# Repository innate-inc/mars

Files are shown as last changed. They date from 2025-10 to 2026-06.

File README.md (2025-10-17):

<div align="center">

<!-- Add your banner image here -->
<!-- ![Mars Robot Banner](./assets/banner.png) -->

# Mars - A Personal AI Robot

*Complete design files and documentation for the Mars robot platform*







</div>

---

> [!WARNING]
> **This is an alpha release** - Breaking changes may occur. DIY builds are as-is without warranty.
> Purchase from us for guaranteed upgrades and full support.

---

## Philosophy

At Innate, we believe every builder should be a part of the robotics revolution, just like they were for the Personal Computer revolution.

To do so, two things are required: making robots **affordable**, but also **intuitive** and **powerful** to build with. MARS is our first platform and comes with every compute and sensor required for a general-purpose robot: navigation, manipulation, interaction with the best of AI.

With it, you can run (and build) VLAs, embodied agents, world models, and every other crazy idea you might have, for a BOM <$1k!

## Key Specifications

### Robotic Arm
- **Degrees of Freedom**: 5-DOF manipulator with modular end effector
- **Reach**: 10 inches (254mm) maximum
- **Payload**: 200g at full extension
- **Integrated Camera**: 150° field of view for vision-based manipulation

### Power
- **Battery Life**: ~5 hours with all systems running (navigation, manipulation, compute) using an 8000mAh battery*
  
*Battery delivered by Innate

For complete specifications, visit the [official documentation](https://docs.innate.bot).

## Repository Structure

This repository contains all the hardware design files you need to build a Mars robot:

### 📁 [Printed Parts](printed-parts/)
3D printable components including shells, layers, arm links, head, and mounting hardware. See the [printed-parts README](printed-parts/README.md) for details.

### 📁 [PCBs](pcbs/)
KiCad projects and production files for the head PCB and main development board. See the [pcbs README](pcbs/README.md) for details.

### 📄 Documentation
- **[Bill of Materials](BOM.md)** - Complete parts list with sourcing information
- **[Assembly Guide](assemblies.zip)** - Step-by-step assembly instructions

## Getting Started

1. **Review the [Bill of Materials](BOM.md)** - Source all required components
2. **Order PCBs** - See [pcbs/README.md](pcbs/README.md) for manufacturing instructions  
3. **3D Print Parts** - See [printed-parts/README.md](printed-parts/README.md) for printing guidelines
4. **Assemble** - Follow the instructions in [assemblies.zip](assemblies.zip)

## Contributing

We welcome contributions from the community! Feel free to:
- 🐛 Report bugs and issues
- 💡 Suggest new features and improvements
- 🔧 Submit pull requests
- 📖 Improve documentation

Please join our [Discord community](https://discord.gg/your-invite-link) to discuss your ideas before making major changes.

---

## 📜 License

This project uses dual licensing to cover hardware and software components:

### Hardware License: CERN-OHL-S-2.0

All hardware designs, PCB files, 3D models, and related documentation in this repository are licensed under the **CERN Open Hardware Licence Version 2 - Strongly Reciprocal** (CERN-OHL-S-2.0).

This is a copyleft license that ensures any modifications or derivative works must also be released under the same license, promoting open collaboration while protecting the open-source nature of the hardware.

📄 [View Hardware License](LICENSE-HARDWARE)  
🔗 [Learn more about CERN-OHL-S](https://ohwr.org/cern_ohl_s_v2.txt)

### Software License: GPL v3

The software components for this robot (to be released separately) are licensed under the **GNU General Public License v3.0** (GPL v3).

This ensures that any software modifications or derivative works remain open source and available to the community.

📄 [View Software License](LICENSE-SOFTWARE) *(Software repository coming soon)*  
🔗 [Learn more about GPL v3](https://www.gnu.org/licenses/gpl-3.0.en.html)

---

<div align="center">

**Built with 💙 by Innate in Palo Alto, California**

[Discord](https://discord.gg/your-invite-link) • [Documentation](https://docs.yoursite.com) • [Website](https://yourwebsite.com)

</div>

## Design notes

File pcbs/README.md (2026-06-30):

# PCBs

KiCad project files and production-ready outputs for all Mars robot circuit boards.

## 📋 Boards

### Head PCB
**Location**: `head-pcb/`

The head PCB controls sensors and actuators in the robot's head assembly.

- **KiCad Project**: [leader.kicad_pro](head-pcb/leader.kicad_pro)
- **Schematic**: [leader.kicad_sch](head-pcb/leader.kicad_sch)
- **PCB Layout**: [leader.kicad_pcb](head-pcb/leader.kicad_pcb)

**Production Files** (`head-pcb/production/`):
- [Gerbers & Drill Files](head-pcb/production/leader.zip)
- [BOM (Bill of Materials)](head-pcb/production/bom.csv)
- [Component Positions](head-pcb/production/positions.csv)
- [Designators Reference](head-pcb/production/designators.csv)
- [IPC Netlist](head-pcb/production/netlist.ipc)

### Main Development Board
**Location**: `main-dev-board/`

The main development board is the brain of the robot, handling computation and motor control."C:\Users\nick\Documents\Innate\mars\pcbs\main-dev-board\MARS%20Dev%20Board.kicad_pro"

- **KiCad Project**: [innate dev pcb.kicad_pro](main-dev-board/MARS%20Dev%20Board.kicad_pro)
- **Schematic**: [innate dev pcb.kicad_sch](main-dev-board/MARS%20Dev%20Board.kicad_sch)
- **PCB Layout**: [innate dev pcb.kicad_pcb](main-dev-board/MARS%20Dev%20Board.kicad_pcb)
- **3D Model**: [innate dev pcb.step](main-dev-board/MARS%20Dev%20Board.step)

**Production Files** (`main-dev-board/production/`):
- [Gerbers & Drill Files](main-dev-board/production/MARS_Dev_Board.zip)
- [BOM (Bill of Materials)](main-dev-board/production/bom.csv)
- [Component Positions](main-dev-board/production/positions.csv)
- [Designators Reference](main-dev-board/production/designators.csv)
- [IPC Netlist](main-dev-board/production/netlist.ipc)

## Design Modifications

To modify the PCB designs:
1. Install [KiCad 7.0+](https://www.kicad.org/)
2. Open the `.kicad_pro` file in KiCad
3. Make your changes to schematic and/or layout
4. Regenerate production files using KiCad's fabrication output tools

## 📐 Fabrication Toolkit

Both boards include `fabrication-toolkit-options.json` for automated production file generation.

## ⚡ Important Notes

- Always verify board revisions match your BOM
- Double-check component orientations before assembly
- Test boards thoroughly before integration
- Refer to the [main BOM](../BOM.md) for complete sourcing information

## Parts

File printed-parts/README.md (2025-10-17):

# Printed Parts

All 3D printable components for the Mars robot. Files are provided in STEP format for maximum compatibility.

## 🏗️ Structure Components

### Shells
- **[shell.STEP](shells/shell.STEP)** - Main outer shell

### Layers
- **[layer1.STEP](layers/layer1.STEP)** - Base layer
- **[layer2.STEP](layers/layer2.STEP)** - Second layer
- **[layer3.STEP](layers/layer3.STEP)** - Third layer
- **[Layer4.STEP](layers/Layer4.STEP)** - Top layer

## 🦾 Arm Components

### Arm Links
- **[link1.STEP](arm/link1.STEP)** - Base link
- **[link2.STEP](arm/link2.STEP)** - Second link
- **[link3.STEP](arm/link3.STEP)** - Third link
- **[link4.STEP](arm/link4.STEP)** - Fourth link
- **[link5.STEP](arm/link5.STEP)** - Fifth link
- **[link61.STEP](arm/link61.STEP)** - Sixth link part 1
- **[link62.STEP](arm/link62.STEP)** - Sixth link part 2

## 🤖 Head Components

- **[head.STEP](heads/head.STEP)** - Robot head assembly

## 🔧 Layer Components

- **[batter_holder_2_cover.STEP](layer-components/batter_holder_2_cover.STEP)** - Battery holder cover
- **[usb_holder.STEP](layer-components/usb_holder.STEP)** - USB cable holder

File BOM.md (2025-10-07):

# Bill of Materials (BOM)

## PRINTED PARTS

| Item | Description | Qty | Link |
|---|---|-----|---|
| 1 | Shell | 1 | [shell.STEP](printed-parts/shells/shell.STEP) |
| 2 | Layer 1 | 1 | [layer1.STEP](printed-parts/layers/layer1.STEP) |
| 3 | Layer 2 | 1 | [layer2.STEP](printed-parts/layers/layer2.STEP) |
| 4 | Layer 3 | 1 | [layer3.STEP](printed-parts/layers/layer3.STEP) |
| 5 | Layer 4 | 1 | [Layer4.STEP](printed-parts/layers/Layer4.STEP) |
| 6 | Head | 1 | [head.STEP](printed-parts/heads/head.STEP) |
| 7 | Battery Cover | 1 | [batter_holder_2_cover.STEP](printed-parts/layer-components/batter_holder_2_cover.STEP) |
| 8 | Link 1 | 1 | [link1.STEP](printed-parts/arm/link1.STEP) |
| 9 | Link 2 | 1 | [link2.STEP](printed-parts/arm/link2.STEP) |
| 10 | Link 3 | 1 | [link3.STEP](printed-parts/arm/link3.STEP) |
| 11 | Link 4 | 1 | [link4.STEP](printed-parts/arm/link4.STEP) |
| 12 | Link 5 | 1 | [link5.STEP](printed-parts/arm/link5.STEP) |
| 13 | Link 6-1 | 1 | [link61.STEP](printed-parts/arm/link61.STEP) |
| 14 | Link 6-2 | 1 | [link62.STEP](printed-parts/arm/link62.STEP) |

## MOTORS and WHEELS

| Item | Description | Manufacturer | Model Number | Qty | Price | Link |
|---|---|---|---|-----|---|---|
| 1 | Dynamixel XL430 | Robotis | XL430-W250-T | 2 | $27.50 | [Product Page](https://www.robotis.us/dynamixel-xl430-w250-t/) |
| 2 | Dynamixel XC430 | Robotis | XC430-T240BB-T | 1 | $137.89 | [Product Page](https://www.robotis.us/dynamixel-xc430-t240bb-t/) |
| 3 | Dynamixel XL330 | Robotis | XL330-M288 | 4 | $27.49 | [Product Page](https://www.robotis.us/dynamixel-xl330-m288-t/) |
| 4 | Waveshare DDSM210 | Waveshare | DDSM210 | 2 | $23.99 | [Product Page](https://www.waveshare.com/ddsm210.htm) |
| 5 | Ball Caster with 3/4″ Metal Ball | Pololu | 955 | 1 | $4.49 | [Product Page](https://www.pololu.com/product/955) |

## CABLES

| Item | Description | Qty | Price | Link |
|---|---|-----|---|---|
| 1 | XT60 Female to T-Plug (Deans) Male Cable 14AWG (8in/200mm) | 1 | $3.99 | [Product Page](https://innov8tivedesigns.com/charge-harness-cable-xt60-female-to-t-plug-male.html) |
| 2 | USB 3.0 Type A to USB C 90 Degree Cable (3.3ft/1m) | 1 | $9.98 | [Product Page](https://a.co/d/eL7heE4) |
| 3 | USB 2.0 to Micro USB Cable (1ft/0.3m) | 1 | $8.99 | [Product Page](https://a.co/d/4h7tGla) |
| 4 | USB 3.0 Type A Male to Male Cable (1.5ft/0.5m) | 1 | $4.99 | [Product Page](https://a.co/d/hsTTd4A) |
| 5 | USB A to USB C Cable 10Gbps (1.6ft) 2-Pack | 1 | $20.78 | [Product Page](https://a.co/d/3ilqBba) |

## SENSORS

| Item | Description | Manufacturer | Model Number | Qty | Price | Link |
|---|---|---|---|-----|---|---|
| 1 | OAK-D W Stereo Depth Camera | Luxonis | OAK-D-W-97 | 1 | $449.99 | [Product Page](https://shop.luxonis.com/products/oak-d-w?variant=44149271265503) |
| 2 | RPLidar A1M8 | Slamtec | A1M8 | 1 | $99.99 | [Product Page](https://www.slamtec.com/en/lidar/a1) |
| 3 | USB Camera | Arducam | B0261 | 1 | $49.99 | [Product Page](https://www.arducam.com/arducam-fisheye-low-light-usb-camera-for-computer-2mp-1080p-imx291-wide-angle-mini-h-264-uvc-video-camera-board-with-microphone.html) |

## LAYER COMPONENTS

| Item | Description | Manufacturer | Qty | Price | Link |
|---|---|---|-----|---|---|
| 1 | Head PCB | JLCPCB | 1 | | [KiCad Project](pcbs/head-pcb/leader.kicad_pro) \| [Production Files](pcbs/head-pcb/production/) |
| 2 | Main PCB | JLCPCB | 1 | | [KiCad Project](pcbs/main-dev-board/innate%20dev%20pcb.kicad_pro) \| [Production Files](pcbs/main-dev-board/production/) |
| 3 | Jetson Orin nano | Nvidia | 1 | $249.00 | [Product Page](https://www.nvidia.com/en-us/autonomous-machines/embedded-systems/jetson-orin/nano-super-developer-kit/) |

## HARDWARE

| Item | Description | Qty |
|---|---|-----|
| 1 | M3x40 Spacers | 9 |
| 2 | M3 Thumb nuts | 4 |
| 3 | M3 x 12 Bolts | 12 |
| 4 | M3 nuts | 20 |
| 5 | M4 x 8 Bolts | 6 |
| 6 | M2.5 x 6 Bolts | 8 |
| 7 | M2.5 x 8 Bolts | 4 |
| 8 | M3 x 8 Bolts | 4 |
| 9 | M3 x 20 Bolts | 4 |
| 10 | M2.5 nuts | 12 |
| 11 | Assorted Hardware | 20 |

## BATTERY

| Item | Description | Manufacturer | Qty | Price | Link |
|---|---|---|-----|---|---|
| 1 | 8000 Mah Lipo | ZEEE Power | 1 | $62.00 | [Product Page](https://a.co/d/5oQBWqG) |

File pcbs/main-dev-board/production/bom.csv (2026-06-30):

Reference | Value | DNP | Exclude from BOM | Exclude from Board | Footprint | LCSC Part #
D2,D5 | SMBJ33CA |  |  |  | SMBJ33CA:DIOM4336X265N | C78420
J7,J19 | 1935161 |  |  |  | TerminalBlock_Phoenix:TerminalBlock_Phoenix_PT-1,5-2-5.0-H_1x02_P5.00mm_Horizontal | C8404
C7 | 10TPB220ML |  |  |  | 10TPB220ML:CAP_10TPB220ML | C347545
L2 | FXL0630-150-M |  |  |  | FXL0630-150-M:INDM7066X300N | C177243
D1 | B340A-13-F |  |  |  | B340A-13-F:DIOM5226X240N | C908680
J6 | XT60PW-M |  |  |  | AMASS_XT60PW-M:AMASS_XT60PW-M | C98732
USB1 | ~ |  |  |  | Connector_USB:USB_C_Receptacle_HRO_TYPE-C-31-M-12 | C165948
U10 | SN74LVC1G125DBV |  |  |  | Package_TO_SOT_SMD:SOT-23-5 | C23654
U9 | AMS1117-3.3 |  |  |  | Package_TO_SOT_SMD:SOT-223-3_TabPin2 | C347222
U8 | CH343P |  |  |  | Package_DFN_QFN:WCH_QFN-16-1EP_3x3mm_P0.5mm_EP1.8x1.8mm | C2846043
U7 | MIC5504-1.8YM5 |  |  |  | Package_TO_SOT_SMD:SOT-23-5 | C3040643
U6 | BTS50010-1TAD |  |  |  | Package_TO_SOT_SMD:TO-263-7_TabPin4 | C2150443
U5 | TPS259482AYWPR |  |  |  | tps25948:YWP0012A-MFG | C22422005
U4 | ICM-20948 |  |  |  | Sensor_Motion:InvenSense_QFN-24_3x3mm_P0.4mm | C726001
U3 | SN74LVC1G126DBV |  |  |  | Package_TO_SOT_SMD:SOT-23-5 | C7834
U2 | MAX98357A |  |  |  | Package_DFN_QFN:TQFN-16-1EP_3x3mm_P0.5mm_EP1.23x1.23mm | C910544
U1 | TPS5430DDA |  |  |  | Package_SO:TI_SO-PowerPAD-8_ThermalVias | C9864
R37,R38 | 100 |  |  |  | Resistor_SMD:R_0402_1005Metric | C25076
R36 | 470 |  |  |  | Resistor_SMD:R_0402_1005Metric | C25167
R35,R40,R41 | 1.8k |  |  |  | Resistor_SMD:R_0402_1005Metric | C25932
R32,R39 | 100k |  |  |  | Resistor_SMD:R_0402_1005Metric | C25741
R28,R29 | 5k1 |  |  |  | Resistor_SMD:R_0402_1005Metric | C25905
R24,R25,R26,R27 | 2.2k |  |  |  | Resistor_SMD:R_0402_1005Metric | C25879
R23 | 1k |  |  |  | Resistor_SMD:R_0402_1005Metric | C11702
R20 | 4 |  |  |  | Resistor_SMD:R_0402_1005Metric | C270603
R18,R19 | 10k |  |  |  | Resistor_SMD:R_0402_1005Metric | C25744
R14 | 42.2k |  |  |  | Resistor_SMD:R_0402_1005Metric | C26979
R13 | 470k |  |  |  | Resistor_SMD:R_0402_1005Metric | C25790
R12 | 887 |  |  |  | Resistor_SMD:R_0402_1005Metric | C474137
R11 | 47k |  |  |  | Resistor_SMD:R_0402_1005Metric | C25792
R10 | 133k |  |  |  | Resistor_SMD:R_0402_1005Metric | C25753
R8,R9,R33,R34 | 10K |  |  |  | Resistor_SMD:R_0402_1005Metric | C25744
R7 | 20K |  |  |  | Resistor_SMD:R_0402_1005Metric | C25765
R6 | 3.24k |  |  |  | Resistor_SMD:R_0603_1608Metric | C22994
R5 | 10k |  |  |  | Resistor_SMD:R_0603_1608Metric | C15401
R3,R21,R22,R30 | 4.7k |  |  |  | Resistor_SMD:R_0402_1005Metric | C25900
R2 | 634K |  |  |  | Resistor_SMD:R_0402_1005Metric | C270588
R1 | 100K |  |  |  | Resistor_SMD:R_0402_1005Metric | C25741
Q5 | CSD18540Q5B |  |  |  | Package_TO_SOT_SMD:TDSON-8-1 | C86513
Q3,Q4,Q6 | 2N7002 |  |  |  | Package_TO_SOT_SMD:SOT-23 | C8545
Q1 | MMBT3906 |  |  |  | Package_TO_SOT_SMD:SOT-23 | C53444
J30 | Conn_02x03_Odd_Even |  |  |  | Connector_PinHeader_2.54mm:PinHeader_2x03_P2.54mm_Vertical | C124384
J23 | Conn_01x02 |  |  |  | Connector_PinSocket_2.54mm:PinSocket_1x02_P2.54mm_Vertical | C18078125
J20,J21 | Conn_01x02 |  |  |  | Connector_JST:JST_VH_B2P-VH_1x02_P3.96mm_Vertical | C160315
J17 | Conn_01x07 |  |  |  | Connector_PinSocket_2.54mm:PinSocket_1x07_P2.54mm_Vertical | C18078130
J14 | Conn_01x13 |  |  |  | Connector_PinSocket_2.54mm:PinSocket_1x13_P2.54mm_Vertical | C2685211
J11 | Conn_01x04 |  |  |  | Connector_PinSocket_2.54mm:PinSocket_1x04_P2.54mm_Vertical | C7499324
J10,J16 | Conn_01x05 |  |  |  | Connector_PinSocket_2.54mm:PinSocket_1x05_P2.54mm_Vertical | C18078128
J8,J9 | Conn_01x14 |  |  |  | Connector_PinSocket_2.54mm:PinSocket_1x14_P2.54mm_Vertical | C18078135
J5,J12,J15,J18 | Conn_01x03 |  |  |  | Connector_PinSocket_2.54mm:PinSocket_1x03_P2.54mm_Vertical | C146243
J3,J4 | Conn_01x03 |  |  |  | Connector_JST:JST_EH_B3B-EH-A_1x03_P2.50mm_Vertical | C398546
J2 | Conn_01x02 |  |  |  | Connector_JST:JST_XH_B2B-XH-A_1x02_P2.50mm_Vertical | C158012
J1 | Conn_02x20_Odd_Even |  |  |  | Connector_PinSocket_2.54mm:PinSocket_2x20_P2.54mm_Vertical | C2682225
IC1 | AP74700QW6-7 |  |  |  | SOT-26:SOT95P280X145-6N | C5381661
FB1,FB2 | FerriteBead |  |  |  | Capacitor_SMD:C_0402_1005Metric_Pad0.74x0.62mm_HandSolder | C85817
D4 | B5819WS |  |  |  | Diode_SMD:D_SOD-323 | C22624
D3,D6,D7,D8,D9 | LED |  |  |  | Diode_SMD:D_0603_1608Metric | C12065
CON1,CON2 | B4B-ZR |  |  |  | B4B-ZR:B4B-ZR | C157997
C38 | 10uF |  |  |  | 10uFTant:CAPMP3516X190N | C7194
C37 | 220uF |  |  |  | Capacitor_SMD:C_Elec_8x10.2 | C341198
C34 | 22nF |  |  |  | Capacitor_SMD:C_0402_1005Metric | C76703
C28 | 470uF |  |  |  | Capacitor_SMD:C_Elec_10x10.2 | C242138
C24 | 22uF |  |  |  | 10uFTant:CAPMP3516X190N | C2158664
C19 | 10uF |  |  |  | Capacitor_SMD:C_0603_1608Metric | C19702
C15,C16,C21,C23,C25,C35 | 1uF |  |  |  | Capacitor_SMD:C_0603_1608Metric | C29936
C13 | 150nF |  |  |  | Capacitor_SMD:C_0402_1005Metric | C5448879
C11,C14 | 10nF |  |  |  | Capacitor_SMD:C_0402_1005Metric | C76702
C10 | 4.3nF |  |  |  | Capacitor_SMD:C_0402_1005Metric | C181747
C9 | 2.2nF |  |  |  | Capacitor_SMD:C_0402_1005Metric | C541386
C8,C12,C17,C18,C20,C22,C26,C27,C30,C39 | .1uF |  |  |  | Capacitor_SMD:C_0402_1005Metric | C56392
C5 | 10nF |  |  |  | Capacitor_SMD:C_0603_1608Metric | C1691
C4,C6,C29 | 10uF |  |  |  | Capacitor_SMD:C_0805_2012Metric | C3039694
C3,C36 | 220pf |  |  |  | Capacitor_SMD:C_0402_1005Metric | C117751
C2 | .1uf |  |  |  | Capacitor_SMD:C_0402_1005Metric | C56392
C1 | 10uf |  |  |  | Capacitor_SMD:C_0603_1608Metric | C19702
BZ1 | Buzzer |  |  |  | Buzzer:XDCR_KXG1205C | C1122355

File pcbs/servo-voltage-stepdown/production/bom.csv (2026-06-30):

Designator | Footprint | Quantity | Value | LCSC Part #
C4 | 0805 | 1 | 22uF | C5674
C5 | 0603 | 1 | 10nF | C1691
C7 | CAP_10TPB220ML | 1 | 10TPB220ML | C347545
D1 | DIOM5226X240N | 1 | B340A-13-F | C908680
J1, J2 | JST_EH_B3B-EH-A_1x03_P2.50mm_Vertical | 2 | Conn_01x03 | C263754
L2 | INDM7066X300N | 1 | FXL0630-150-M | C177243
R5 | 0603 | 1 | 10k | C15401
R6 | 0603 | 1 | 3.24k | C22994
U1 | TI_SO-PowerPAD-8_ThermalVias | 1 | TPS5430DDA | C9864

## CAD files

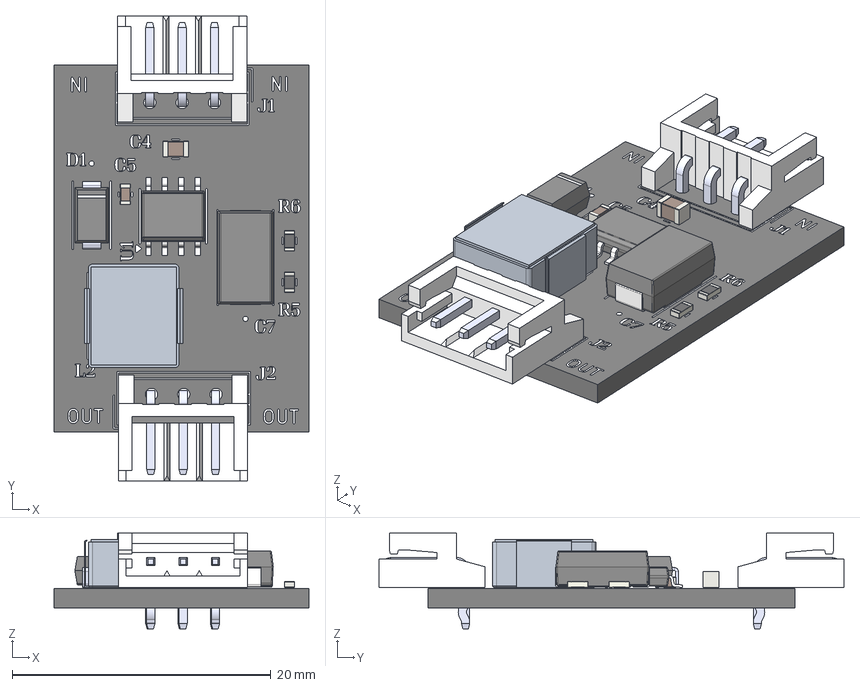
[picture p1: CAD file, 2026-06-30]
pcbs/servo-voltage-stepdown/Servo Voltage Stepdown.step
19.7 x 36.0 x 7.40 mm
B340A-13-F
R_0603_1608Metric x 2
C_0805_2012Metric
S3B-EH x 2
Inductor
C_0603_1608Metric
10TPB220ML
BODY-SO
LEAD-SO x 8
THERMALPAD-SO
Servo Voltage Stepdown_silkscreen
Servo Voltage Stepdown_PCB

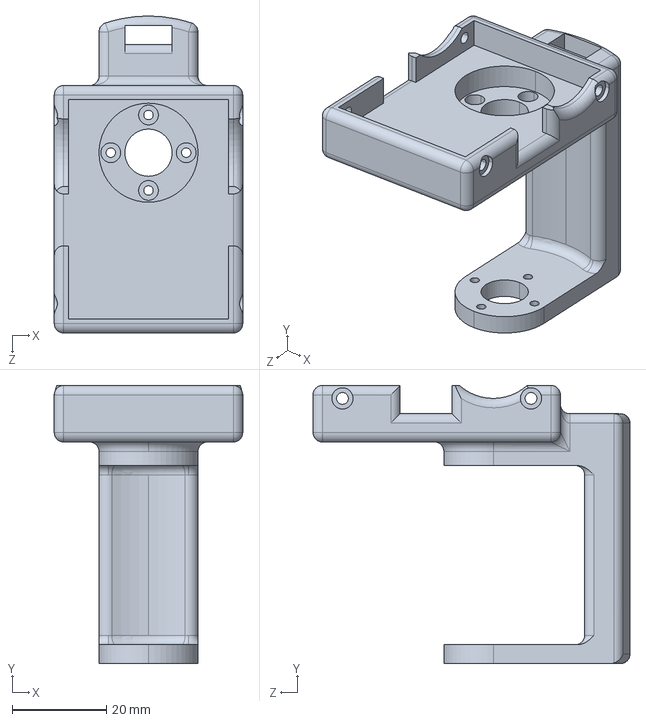
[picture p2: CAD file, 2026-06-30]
printed-parts/arm/link1.STEP
40.0 x 59.0 x 67.2 mm

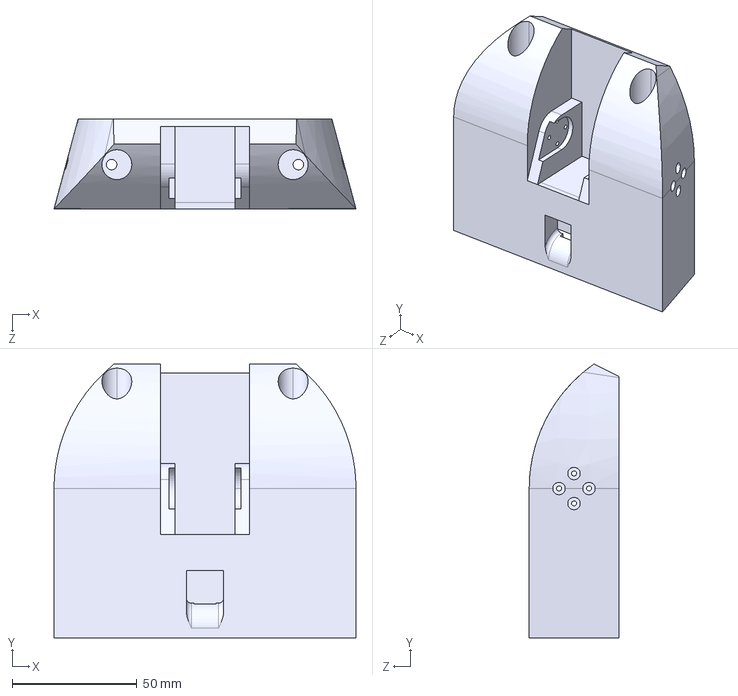
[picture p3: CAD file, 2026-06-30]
printed-parts/head/head.STEP
121.3 x 110.0 x 36.0 mm

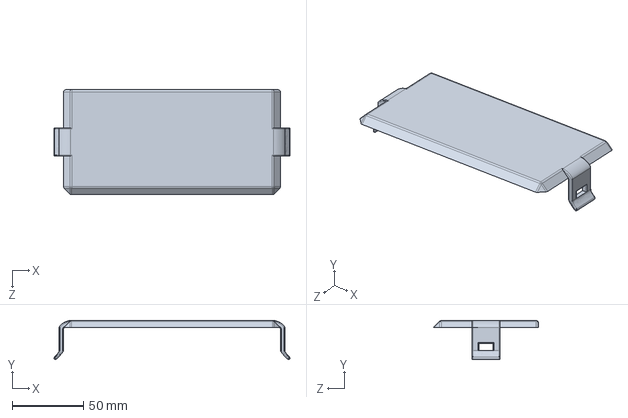
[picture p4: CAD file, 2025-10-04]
printed-parts/layer-components/battery-cover.STEP
165.7 x 27.4 x 74.0 mm

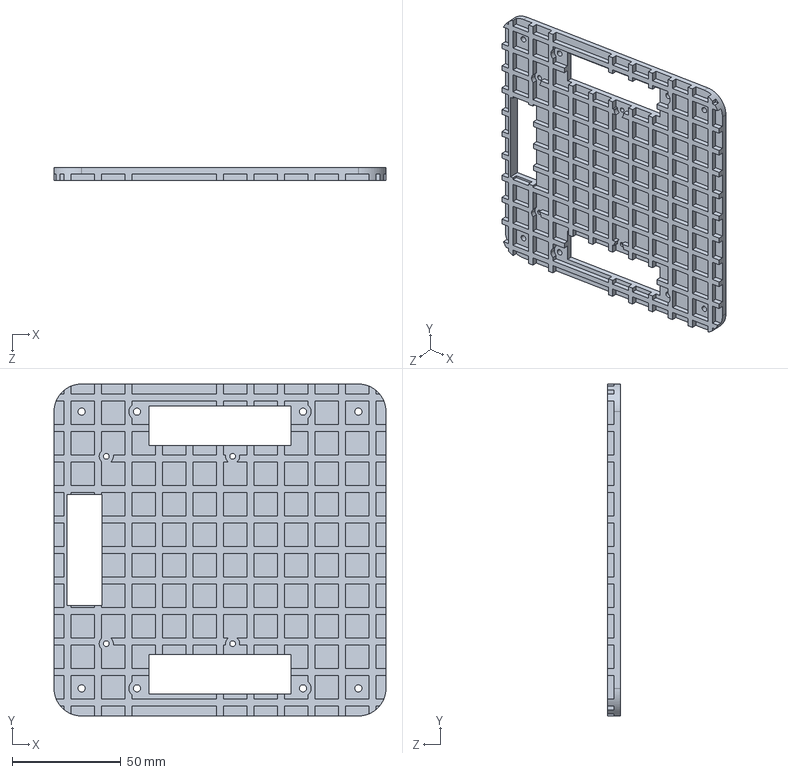
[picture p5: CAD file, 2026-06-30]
printed-parts/layers/layer2.STEP
152.4 x 152.4 x 6.17 mm

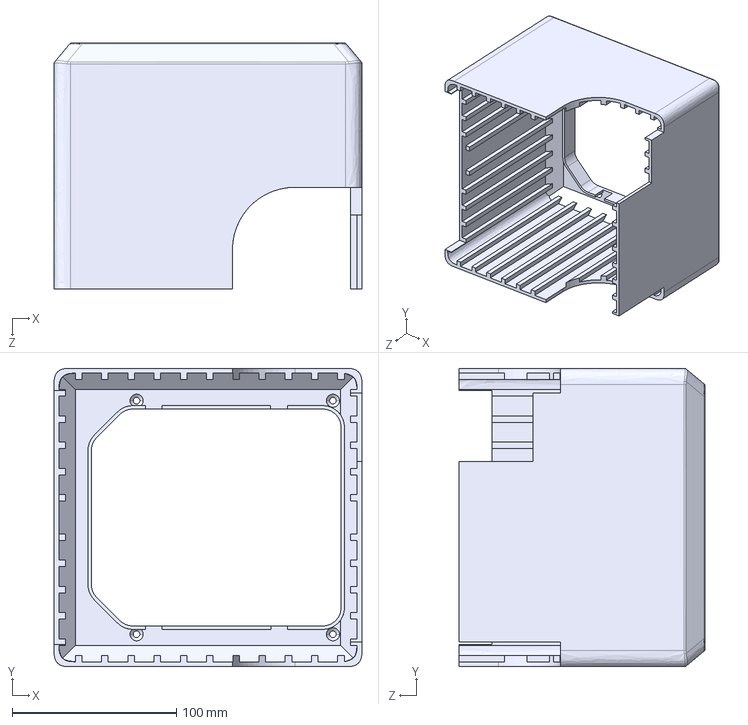
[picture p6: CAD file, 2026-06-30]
printed-parts/shells/shell.STEP
187.8 x 182.0 x 150.0 mm

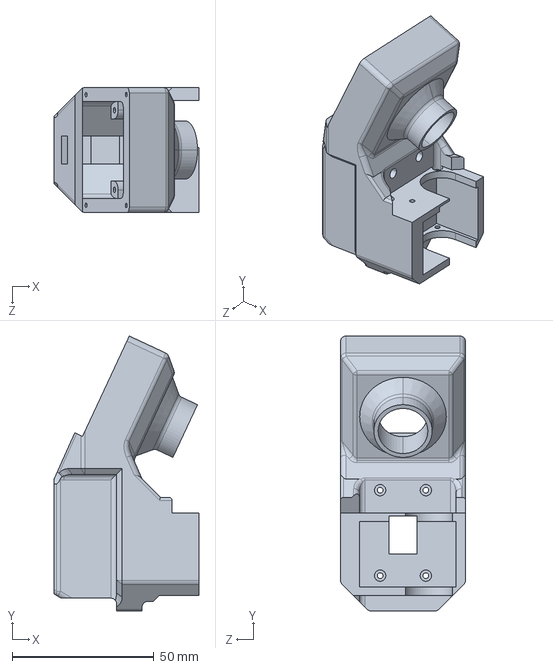
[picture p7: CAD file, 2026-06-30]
printed-parts/arm/link5.STEP
51.0 x 96.8 x 44.0 mm

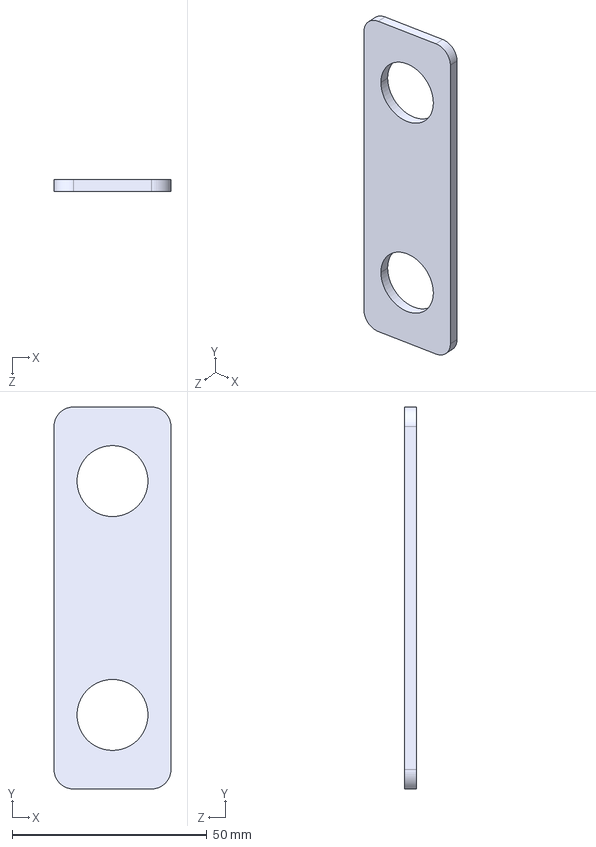
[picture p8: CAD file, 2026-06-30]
printed-parts/head/cover.STEP
30.0 x 98.0 x 3.00 mm

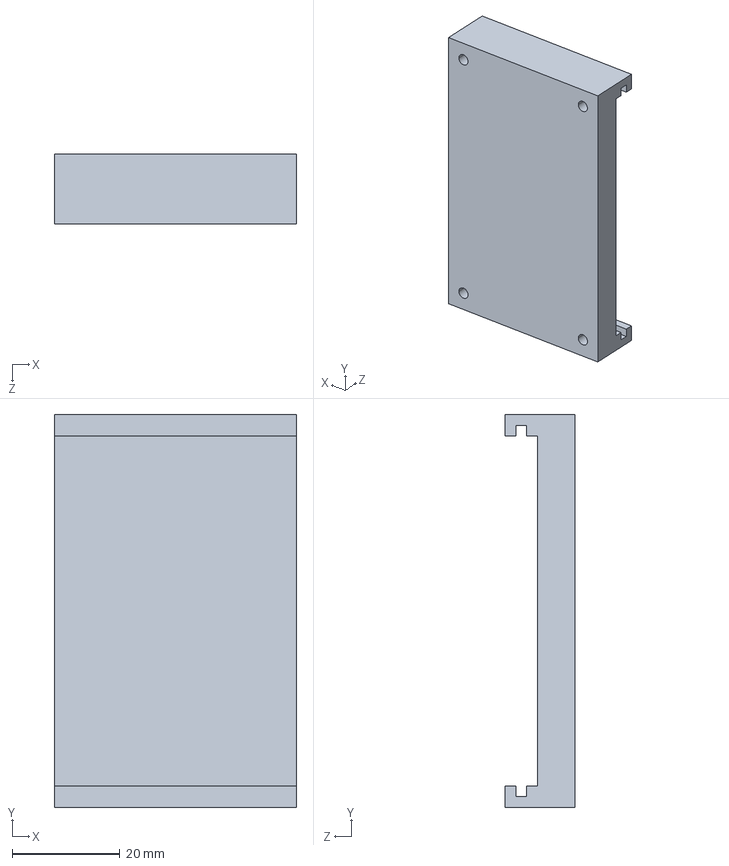
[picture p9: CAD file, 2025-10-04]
printed-parts/layer-components/usb-holder.STEP
45.0 x 73.0 x 13.0 mm

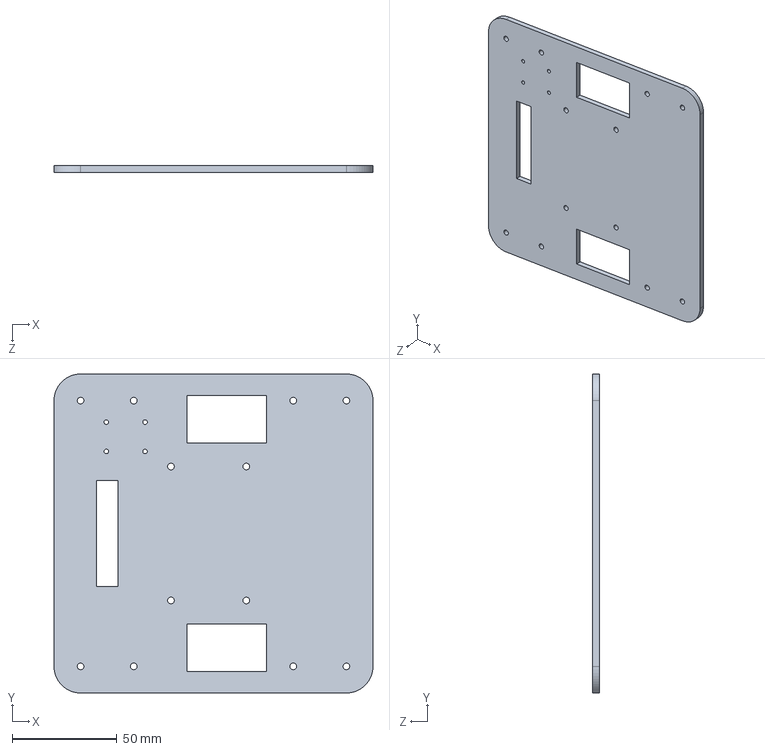
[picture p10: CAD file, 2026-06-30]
printed-parts/layers/layer3.STEP
152.4 x 152.4 x 3.17 mm

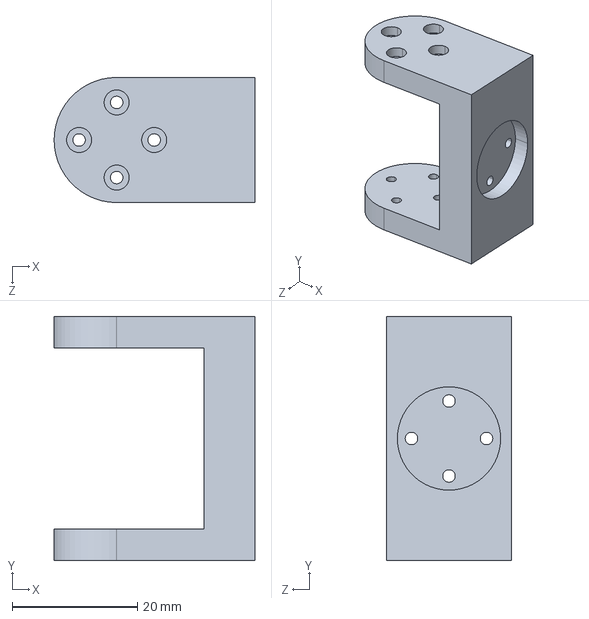
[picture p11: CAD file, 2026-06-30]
printed-parts/arm/link4.STEP
32.1 x 39.0 x 20.0 mm

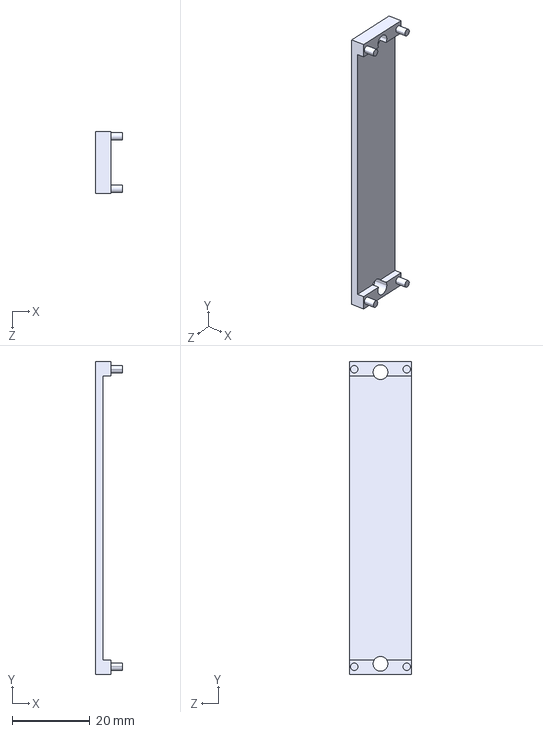
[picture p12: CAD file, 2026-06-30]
printed-parts/head/camera_offset.STEP
7.00 x 80.5 x 16.0 mm

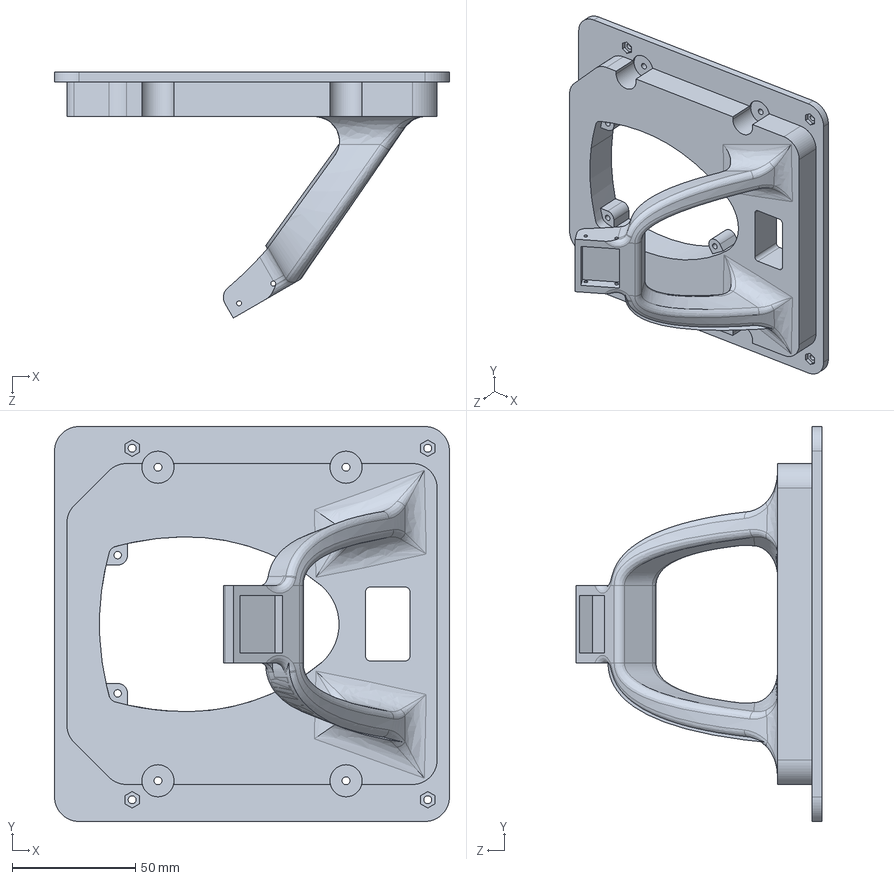
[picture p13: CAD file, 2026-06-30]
printed-parts/layers/Layer4.STEP
160.0 x 160.0 x 99.7 mm

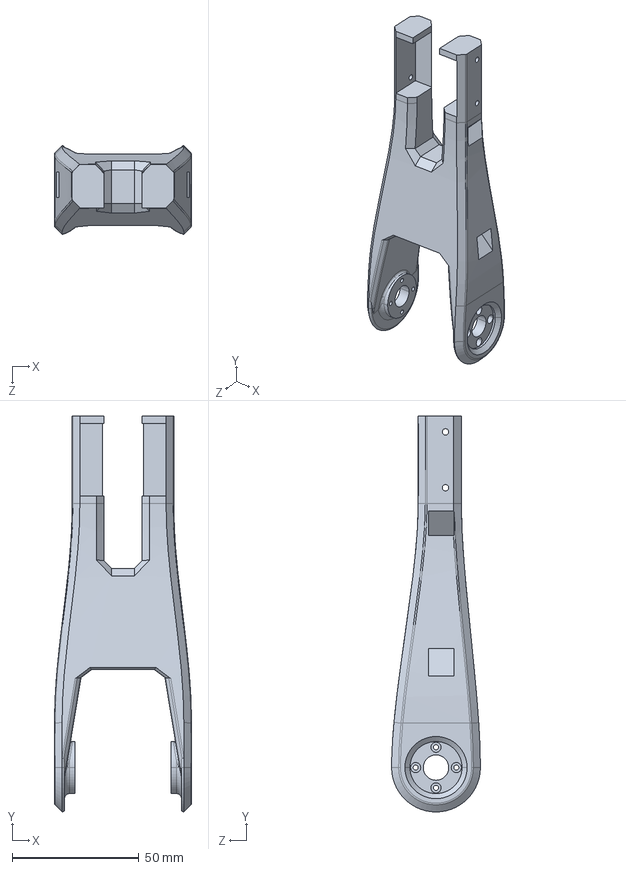
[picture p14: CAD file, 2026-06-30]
printed-parts/arm/link2.STEP
54.0 x 156.0 x 35.0 mm

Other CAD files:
printed-parts/layers/layer1.STEP
printed-parts/arm/link62.STEP
printed-parts/arm/link3.STEP
printed-parts/arm/link61.STEP
printed-parts/arm/link5cap.STEP

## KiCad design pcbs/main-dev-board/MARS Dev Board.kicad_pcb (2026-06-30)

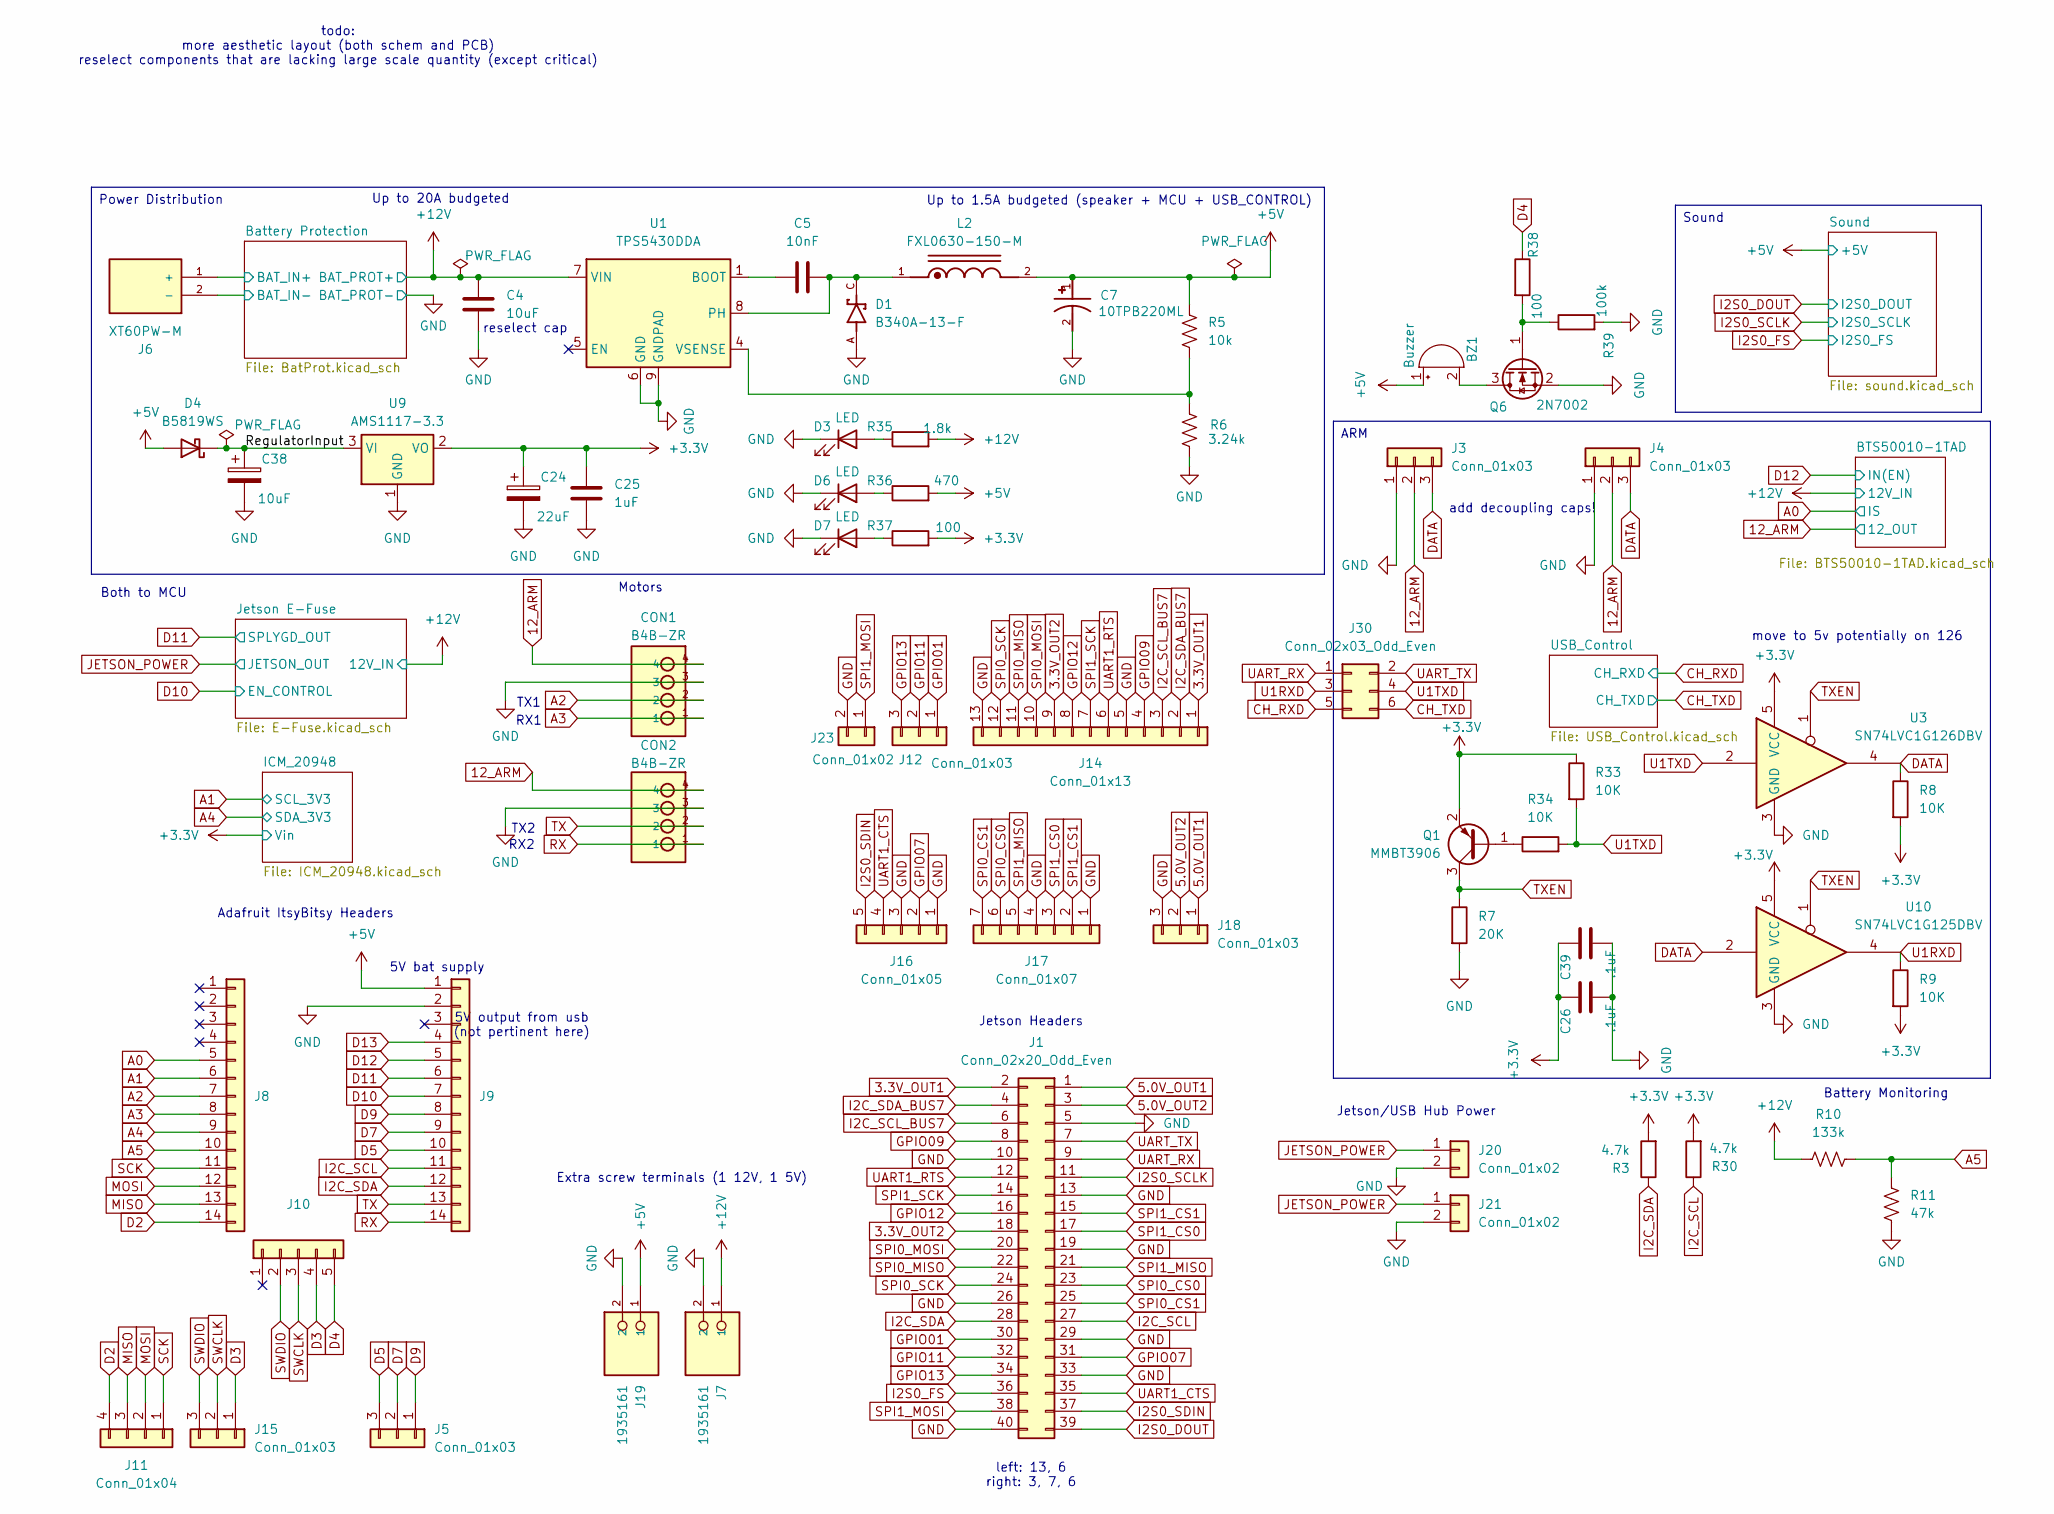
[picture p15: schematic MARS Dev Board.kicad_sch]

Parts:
BZ1: Buzzer; XDCR_KXG1205C; LCSC Part # C1122355
C4: 10uF; C_0805_2012Metric; LCSC Part # C3039694
C5: 10nF; C_0603_1608Metric; LCSC Part # C1691
C7: 10TPB220ML; CAP_10TPB220ML; PARTREV 30-Nov-20; LCSC Part # C347545
C24: 22uF; CAPMP3516X190N; LCSC Part # C2158664
C25: 1uF; C_0603_1608Metric; LCSC Part # C29936
C26, C39: .1uF; C_0402_1005Metric; LCSC Part # C56392
C38: 10uF; CAPMP3516X190N; LCSC Part # C7194
CON1, CON2: B4B-ZR; LCSC Part # C157997
D1: B340A-13-F; DIOM5226X240N; PARTREV 17-2; LCSC Part # C908680
D3, D6, D7: LED; D_0603_1608Metric; LCSC Part # C12065
D4: B5819WS; D_SOD-323; LCSC Part # C22624
J1: Conn_02x20_Odd_Even; PinSocket_2x20_P2.54mm_Vertical; LCSC Part # C2682225
J3, J4: Conn_01x03; JST_EH_B3B-EH-A_1x03_P2.50mm_Vertical; LCSC Part # C398546
J5, J12, J15, J18: Conn_01x03; PinSocket_1x03_P2.54mm_Vertical; LCSC Part # C146243
J6: XT60PW-M; AMASS_XT60PW-M; PARTREV V1.2; LCSC Part # C98732
J7, J19: 1935161; TerminalBlock_Phoenix_PT-1,5-2-5.0-H_1x02_P5.00mm_Horizontal; PARTREV 14.12.2022; LCSC Part # C8404
J8, J9: Conn_01x14; PinSocket_1x14_P2.54mm_Vertical; LCSC Part # C18078135
J10, J16: Conn_01x05; PinSocket_1x05_P2.54mm_Vertical; LCSC Part # C18078128
J11: Conn_01x04; PinSocket_1x04_P2.54mm_Vertical; LCSC Part # C7499324
J14: Conn_01x13; PinSocket_1x13_P2.54mm_Vertical; LCSC Part # C2685211
J17: Conn_01x07; PinSocket_1x07_P2.54mm_Vertical; LCSC Part # C18078130
J20, J21: Conn_01x02; JST_VH_B2P-VH_1x02_P3.96mm_Vertical; LCSC Part # C160315
J23: Conn_01x02; PinSocket_1x02_P2.54mm_Vertical; LCSC Part # C18078125
J30: Conn_02x03_Odd_Even; PinHeader_2x03_P2.54mm_Vertical; LCSC Part # C124384
L2: FXL0630-150-M; INDM7066X300N; PARTREV A; LCSC Part # C177243
Q1: MMBT3906; SOT-23; LCSC Part # C53444
Q6: 2N7002; SOT-23; LCSC Part # C8545
R3, R30: 4.7k; R_0402_1005Metric; LCSC Part # C25900
R5: 10k; R_0603_1608Metric; LCSC Part # C15401
R6: 3.24k; R_0603_1608Metric; LCSC Part # C22994
R7: 20K; R_0402_1005Metric; LCSC Part # C25765
R8, R9, R33, R34: 10K; R_0402_1005Metric; LCSC Part # C25744
R10: 133k; R_0402_1005Metric; LCSC Part # C25753
R11: 47k; R_0402_1005Metric; LCSC Part # C25792
R35: 1.8k; R_0402_1005Metric; LCSC Part # C25932
R36: 470; R_0402_1005Metric; LCSC Part # C25167
R37, R38: 100; R_0402_1005Metric; LCSC Part # C25076
R39: 100k; R_0402_1005Metric; LCSC Part # C25741
U1: TPS5430DDA; TI_SO-PowerPAD-8_ThermalVias; LCSC Part # C9864
U3: SN74LVC1G126DBV; SOT-23-5; LCSC Part # C7834
U9: AMS1117-3.3; SOT-223-3_TabPin2; LCSC Part # C347222
U10: SN74LVC1G125DBV; SOT-23-5; LCSC Part # C23654

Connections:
3.3V_OUT1: J1.2, J14.1
3.3V_OUT2: J1.18, J14.9
5.0V_OUT1: J1.1, J18.1
5.0V_OUT2: J1.3, J18.2
12_ARM: CON1.4, CON2.4, J3.2, J4.2; also elsewhere on the board
+3.3V: C24.1, C25.1, C26.1, C39.1, Q1.2 (E), R3.2, R8.2, R9.2, R30.2, R33.1, R37.2, U3.5 (VCC), U9.2 (VO), U10.5 (VCC); also elsewhere on the board
+5V: BZ1.1 (+), C7.1, D4.2 (A), J9.1, J19.1, L2.2, R5.1, R36.2; also elsewhere on the board
+12V: C4.1, J7.1, R10.1, R35.2, U1.7 (VIN); also elsewhere on the board
/Battery Protection/BAT_IN+: J6.1 (+); also elsewhere on the board
/RegulatorInput: C38.1, D4.1 (K), U9.3 (VI)
A0: J8.5; also elsewhere on the board
A1: J8.6; also elsewhere on the board
A2: CON1.2, J8.7
A3: CON1.1, J8.8
A4: J8.9; also elsewhere on the board
A5: J8.10, R10.2, R11.1
CH_RXD: J30.5; also elsewhere on the board
CH_TXD: J30.6; also elsewhere on the board
D2: J8.14, J11.4
D3: J10.4, J15.1
D4: J10.5, R38.1
D5: J5.3, J9.10
D7: J5.2, J9.9
D9: J5.1, J9.8
D10: J9.7; also elsewhere on the board
D11: J9.6; also elsewhere on the board
D12: J9.5; also elsewhere on the board
D13: J9.4
DATA: J3.3, J4.3, R8.1, U3.4, U10.2
GND: C4.2, C7.2, C24.2, C25.2, C26.2, C38.2, C39.2, CON1.3, CON2.3, D1.A, D3.1 (K), D6.1 (K), D7.1 (K), J1.5, J1.10, J1.13, J1.19, J1.26, J1.29, J1.33, J1.40, J3.1, J4.1, J6.2 (-), J7.2, J9.2, J14.5, J14.13, J16.1, J16.3, J17.1, J17.4, J18.3, J19.2, J20.2, J21.2, J23.2, Q6.2 (S), R6.2, R7.2, R11.2, R39.2, U1.6 (GND), U1.9 (GNDPAD), U3.3 (GND), U9.1 (GND), U10.3 (GND); also elsewhere on the board
GPIO01: J1.30, J12.1
GPIO07: J1.31, J16.2
GPIO09: J1.8, J14.4
GPIO11: J1.32, J12.2
GPIO12: J1.16, J14.8
GPIO13: J1.34, J12.3
I2C_SCL: J1.27, J9.11, R30.1
I2C_SCL_BUS7: J1.6, J14.3
I2C_SDA: J1.28, J9.12, R3.1
I2C_SDA_BUS7: J1.4, J14.2
I2S0_DOUT: J1.39; also elsewhere on the board
I2S0_FS: J1.36; also elsewhere on the board
I2S0_SCLK: J1.11; also elsewhere on the board
I2S0_SDIN: J1.37, J16.5
JETSON_POWER: J20.1, J21.1; also elsewhere on the board
MISO: J8.13, J11.3
MOSI: J8.12, J11.2
unnamed: BZ1.2 (-), Q6.3 (D)
unnamed: D3.2 (A), R35.1
unnamed: D6.2 (A), R36.1
unnamed: D7.2 (A), R37.1
unnamed: Q1.1 (B), R34.1
unnamed: Q6.1 (G), R38.2, R39.1
unnamed: C5.1, U1.1 (BOOT)
unnamed: C5.2, D1.C, L2.1, U1.8 (PH)
unnamed: R5.2, R6.1, U1.4 (VSENSE)
RX: CON2.1, J9.14
SCK: J8.11, J11.1
SPI0_CS0: J1.23, J17.6
SPI0_CS1: J1.25, J17.7
SPI0_MISO: J1.22, J14.11
SPI0_MOSI: J1.20, J14.10
SPI0_SCK: J1.24, J14.12
SPI1_CS0: J1.17, J17.3
SPI1_CS1: J1.15, J17.2
SPI1_MISO: J1.21, J17.5
SPI1_MOSI: J1.38, J23.1
SPI1_SCK: J1.14, J14.7
SWCLK: J10.3, J15.2
SWDIO: J10.2, J15.3
TX: CON2.2, J9.13
TXEN: Q1.3 (C), R7.1, U3.1, U10.1
U1RXD: J30.3, R9.1, U10.4
U1TXD: J30.4, R33.2, R34.2, U3.2
UART1_CTS: J1.35, J16.4
UART1_RTS: J1.12, J14.6
UART_RX: J1.9, J30.1
UART_TX: J1.7, J30.2

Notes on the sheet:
Adafruit ItsyBitsy Headers
Battery Monitoring
Up to 20A budgeted
Both to MCU
5V output from usb (not pertinent here)
Extra screw terminals (1 12V, 1 5V)
Jetson/USB Hub Power
RX2
5V bat supply
TX1
add decoupling caps!
Jetson Headers
left: 13, 6 right: 3, 7, 6
TX2
reselect cap
RX1
Motors
move to 5v potentially on 126
Up to 1.5A budgeted (speaker + MCU + USB_CONTROL)
todo: more aesthetic layout (both schem and PCB) reselect components that are lacking large scale quantity (except critical)
Power Distribution
Sound
ARM

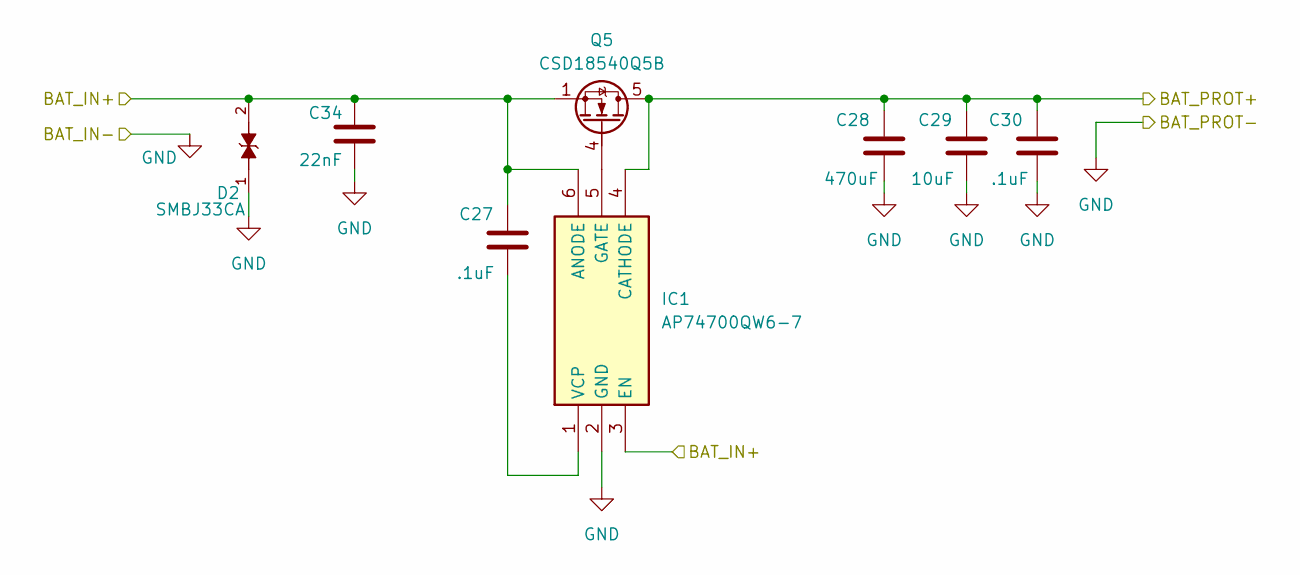
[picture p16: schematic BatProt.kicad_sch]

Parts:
C27, C30: .1uF; C_0402_1005Metric; LCSC Part # C56392
C28: 470uF; C_Elec_10x10.2; LCSC Part # C242138
C29: 10uF; C_0805_2012Metric; LCSC Part # C3039694
C34: 22nF; C_0402_1005Metric; LCSC Part # C76703
D2: SMBJ33CA; DIOM4336X265N; PARTREV I2102; LCSC Part # C78420
IC1: AP74700QW6-7; SOT95P280X145-6N; Manufacturer_Part_Number AP74700QW6-7; Mouser Part Number 621-AP74700QW6-7
Q5: CSD18540Q5B; TDSON-8-1; LCSC Part # C86513

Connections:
+12V: C28.1, C29.1, C30.1, IC1.4 (CATHODE), Q5.5 (D); also elsewhere on the board
/Battery Protection/BAT_IN+: C27.1, C34.1, D2.2, IC1.3 (EN), IC1.6 (ANODE), Q5.1 (S), Q5.2 (S), Q5.3 (S); also elsewhere on the board
GND: C28.2, C29.2, C30.2, C34.2, D2.1, IC1.2 (GND); also elsewhere on the board
unnamed: IC1.5 (GATE), Q5.4 (G)
unnamed: C27.2, IC1.1 (VCP)

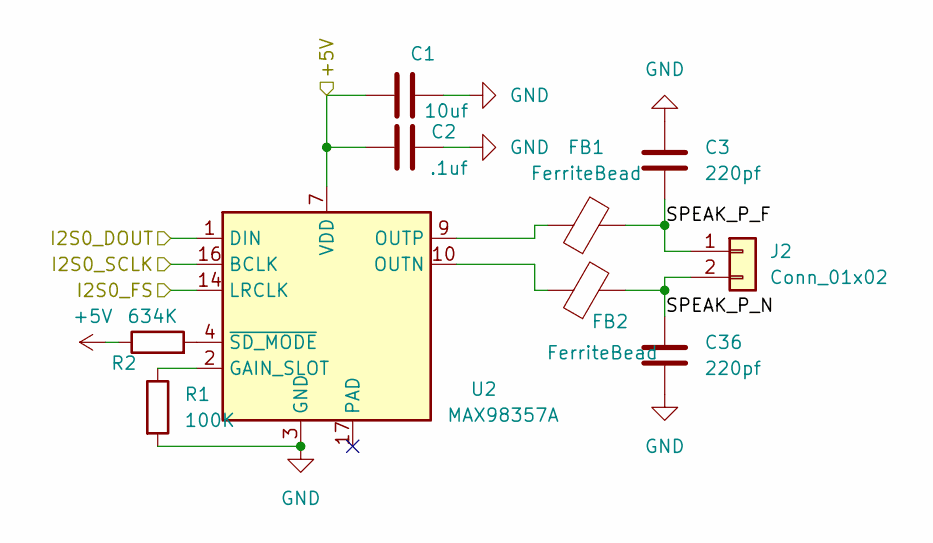
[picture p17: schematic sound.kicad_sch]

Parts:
C1: 10uf; C_0603_1608Metric; LCSC Part # C19702
C2: .1uf; C_0402_1005Metric; LCSC Part # C56392
C3, C36: 220pf; C_0402_1005Metric; LCSC Part # C117751
FB1, FB2: FerriteBead; C_0402_1005Metric_Pad0.74x0.62mm_HandSolder; LCSC Part # C85817
J2: Conn_01x02; JST_XH_B2B-XH-A_1x02_P2.50mm_Vertical; LCSC Part # C158012
R1: 100K; R_0402_1005Metric; LCSC Part # C25741
R2: 634K; R_0402_1005Metric; LCSC Part # C270588
U2: MAX98357A; TQFN-16-1EP_3x3mm_P0.5mm_EP1.23x1.23mm; LCSC Part # C910544

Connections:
+5V: C1.1, C2.1, R2.1, U2.7 (VDD), U2.8 (VDD); also elsewhere on the board
/Sound/SPEAK_P_F: C3.2, FB1.2, J2.1
/Sound/SPEAK_P_N: C36.1, FB2.2, J2.2
GND: C1.2, C2.2, C3.1, C36.2, R1.2, U2.3 (GND), U2.11 (GND), U2.15 (GND); also elsewhere on the board
I2S0_DOUT: U2.1 (DIN); also elsewhere on the board
I2S0_FS: U2.14 (LRCLK); also elsewhere on the board
I2S0_SCLK: U2.16 (BCLK); also elsewhere on the board
unnamed: R1.1, U2.2 (GAIN_SLOT)
unnamed: FB2.1, U2.10 (OUTN)
unnamed: FB1.1, U2.9 (OUTP)
unnamed: R2.2, U2.4 (~SD_MODE)

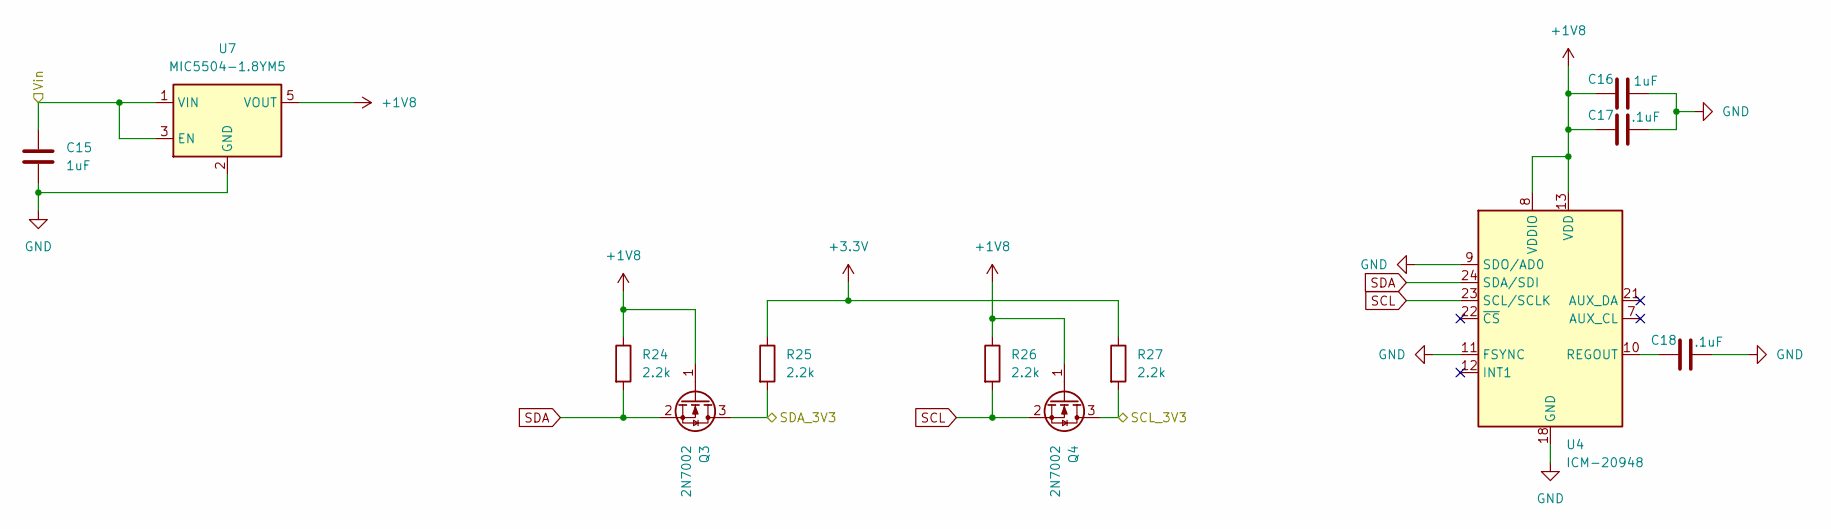
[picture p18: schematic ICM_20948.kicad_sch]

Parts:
C15, C16: 1uF; C_0603_1608Metric; LCSC Part # C29936
C17, C18: .1uF; C_0402_1005Metric; LCSC Part # C56392
Q3, Q4: 2N7002; SOT-23; LCSC Part # C8545
R24, R25, R26, R27: 2.2k; R_0402_1005Metric; LCSC Part # C25879
U4: ICM-20948; InvenSense_QFN-24_3x3mm_P0.4mm; LCSC Part # C726001
U7: MIC5504-1.8YM5; SOT-23-5; LCSC Part # C3040643

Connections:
+1V8: C16.1, C17.1, Q3.1 (G), Q4.1 (G), R24.1, R26.1, U4.8 (VDDIO), U4.13 (VDD), U7.5 (VOUT)
+3.3V: C15.1, R25.1, R27.1, U7.1 (VIN), U7.3 (EN); also elsewhere on the board
A1: Q4.3 (D), R27.2; also elsewhere on the board
A4: Q3.3 (D), R25.2; also elsewhere on the board
GND: C15.2, C16.2, C17.2, C18.2, U4.9 (SDO/AD0), U4.11 (FSYNC), U4.18 (GND), U4.20 (GND), U7.2 (GND); also elsewhere on the board
unnamed: C18.1, U4.10 (REGOUT)
SCL: Q4.2 (S), R26.2, U4.23 (SCL/SCLK)
SDA: Q3.2 (S), R24.2, U4.24 (SDA/SDI)

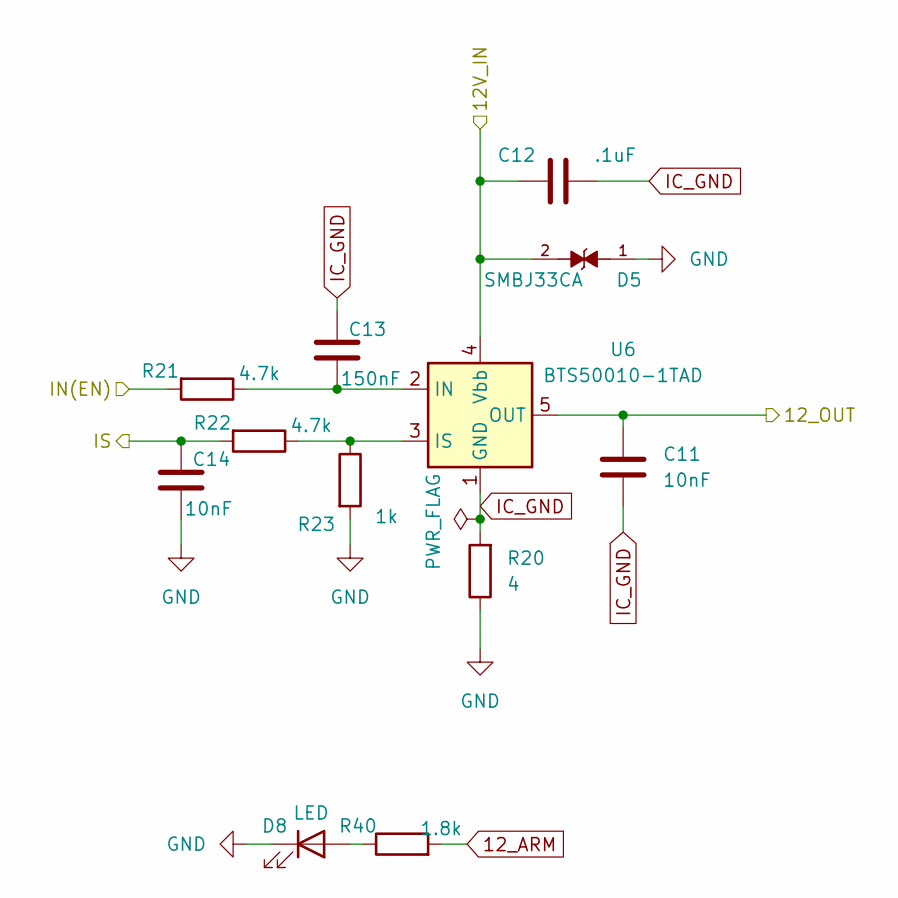
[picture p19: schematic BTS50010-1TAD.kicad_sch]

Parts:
C11, C14: 10nF; C_0402_1005Metric; LCSC Part # C76702
C12: .1uF; C_0402_1005Metric; LCSC Part # C56392
C13: 150nF; C_0402_1005Metric; LCSC Part # C5448879
D5: SMBJ33CA; DIOM4336X265N; PARTREV I2102; LCSC Part # C78420
D8: LED; D_0603_1608Metric; LCSC Part # C12065
R20: 4; R_0402_1005Metric; LCSC Part # C270603
R21, R22: 4.7k; R_0402_1005Metric; LCSC Part # C25900
R23: 1k; R_0402_1005Metric; LCSC Part # C11702
R40: 1.8k; R_0402_1005Metric; LCSC Part # C25932
U6: BTS50010-1TAD; TO-263-7_TabPin4; LCSC Part # C2150443

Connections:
12_ARM: C11.1, R40.2, U6.5 (OUT), U6.6 (OUT), U6.7 (OUT); also elsewhere on the board
+12V: C12.1, D5.2, U6.4 (Vbb); also elsewhere on the board
A0: C14.1, R22.2; also elsewhere on the board
D12: R21.2; also elsewhere on the board
GND: C14.2, D5.1, D8.1 (K), R20.1, R23.2; also elsewhere on the board
IC_GND: C11.2, C12.2, C13.1, R20.2, U6.1 (GND)
unnamed: D8.2 (A), R40.1
unnamed: C13.2, R21.1, U6.2 (IN)
unnamed: R22.1, R23.1, U6.3 (IS)

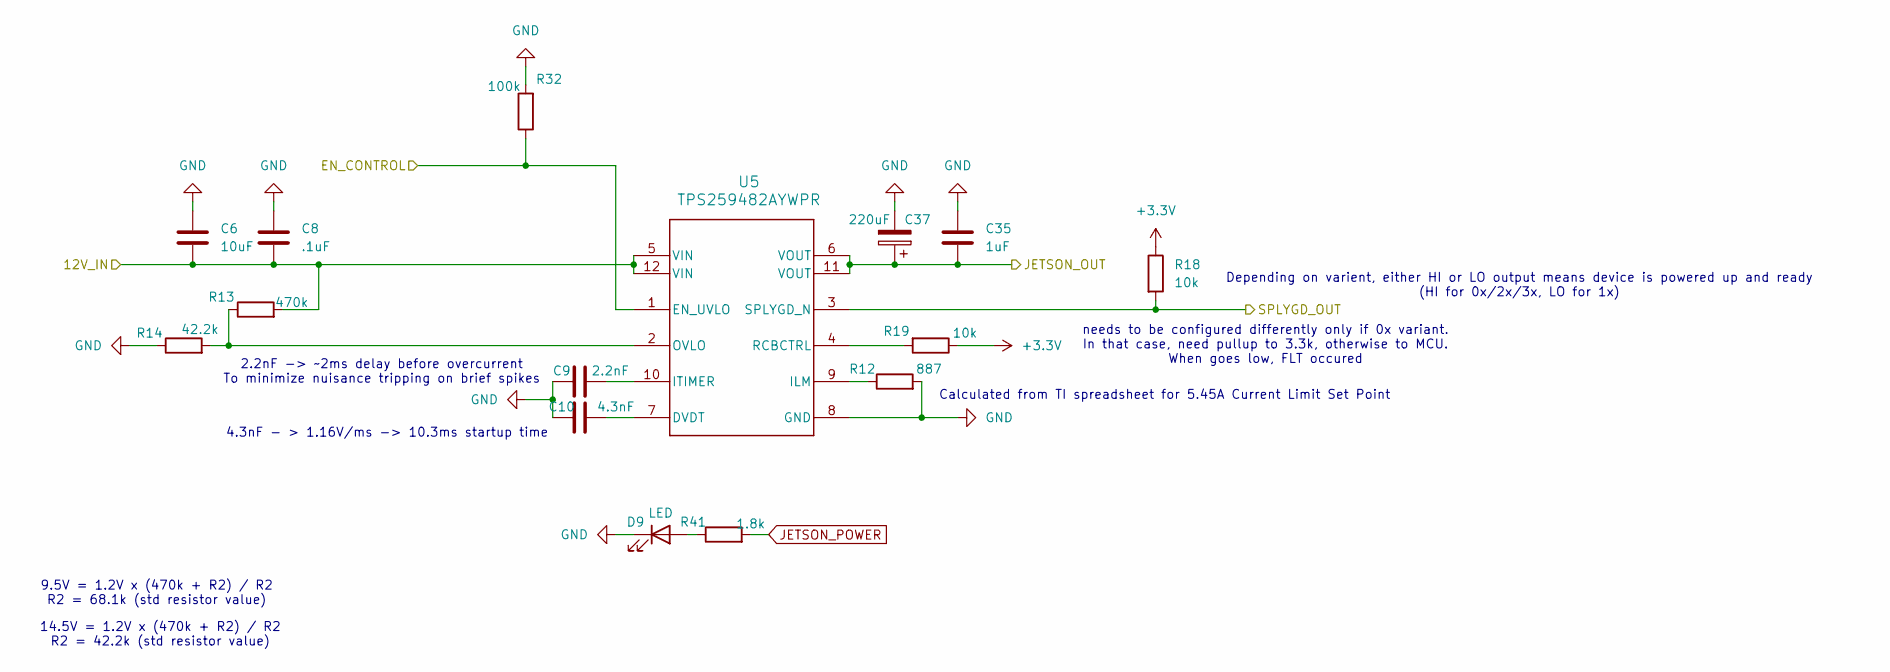
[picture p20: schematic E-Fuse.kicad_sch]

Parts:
C6: 10uF; C_0805_2012Metric; LCSC Part # C3039694
C8: .1uF; C_0402_1005Metric; LCSC Part # C56392
C9: 2.2nF; C_0402_1005Metric; LCSC Part # C541386
C10: 4.3nF; C_0402_1005Metric; LCSC Part # C181747
C35: 1uF; C_0603_1608Metric; LCSC Part # C29936
C37: 220uF; C_Elec_8x10.2; LCSC Part # C341198
D9: LED; D_0603_1608Metric; LCSC Part # C12065
R12: 887; R_0402_1005Metric; LCSC Part # C474137
R13: 470k; R_0402_1005Metric; LCSC Part # C25790
R14: 42.2k; R_0402_1005Metric; LCSC Part # C26979
R18, R19: 10k; R_0402_1005Metric; LCSC Part # C25744
R32: 100k; R_0402_1005Metric; LCSC Part # C25741
R41: 1.8k; R_0402_1005Metric; LCSC Part # C25932
U5: TPS259482AYWPR; YWP0012A-MFG; LCSC Part # C22422005

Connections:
+3.3V: R18.1, R19.1; also elsewhere on the board
+12V: C6.2, C8.2, R13.2, U5.5 (VIN), U5.12 (VIN); also elsewhere on the board
D10: R32.1, U5.1 (EN_UVLO); also elsewhere on the board
D11: R18.2, U5.3 (SPLYGD_N); also elsewhere on the board
GND: C6.1, C8.1, C9.1, C10.1, C35.1, C37.2, D9.1 (K), R12.2, R14.1, R32.2, U5.8 (GND); also elsewhere on the board
JETSON_POWER: C35.2, C37.1, R41.2, U5.6 (VOUT), U5.11 (VOUT); also elsewhere on the board
unnamed: D9.2 (A), R41.1
unnamed: C10.2, U5.7 (DVDT)
unnamed: R12.1, U5.9 (ILM)
unnamed: C9.2, U5.10 (ITIMER)
unnamed: R13.1, R14.2, U5.2 (OVLO)
unnamed: R19.2, U5.4 (RCBCTRL)

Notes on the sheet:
14.5V = 1.2V x (470k + R2) / R2 R2 = 42.2k (std resistor value)
Calculated from TI spreadsheet for 5.45A Current Limit Set Point
Depending on varient, either HI or LO output means device is powered up and ready (HI for 0x/2x/3x, LO for 1x)
2.2nF -> ~2ms delay before overcurrent To minimize nuisance tripping on brief spikes
9.5V = 1.2V x (470k + R2) / R2 R2 = 68.1k (std resistor value)
4.3nF - > 1.16V/ms -> 10.3ms startup time
needs to be configured differently only if 0x variant. In that case, need pullup to 3.3k, otherwise to MCU. When goes low, FLT occured

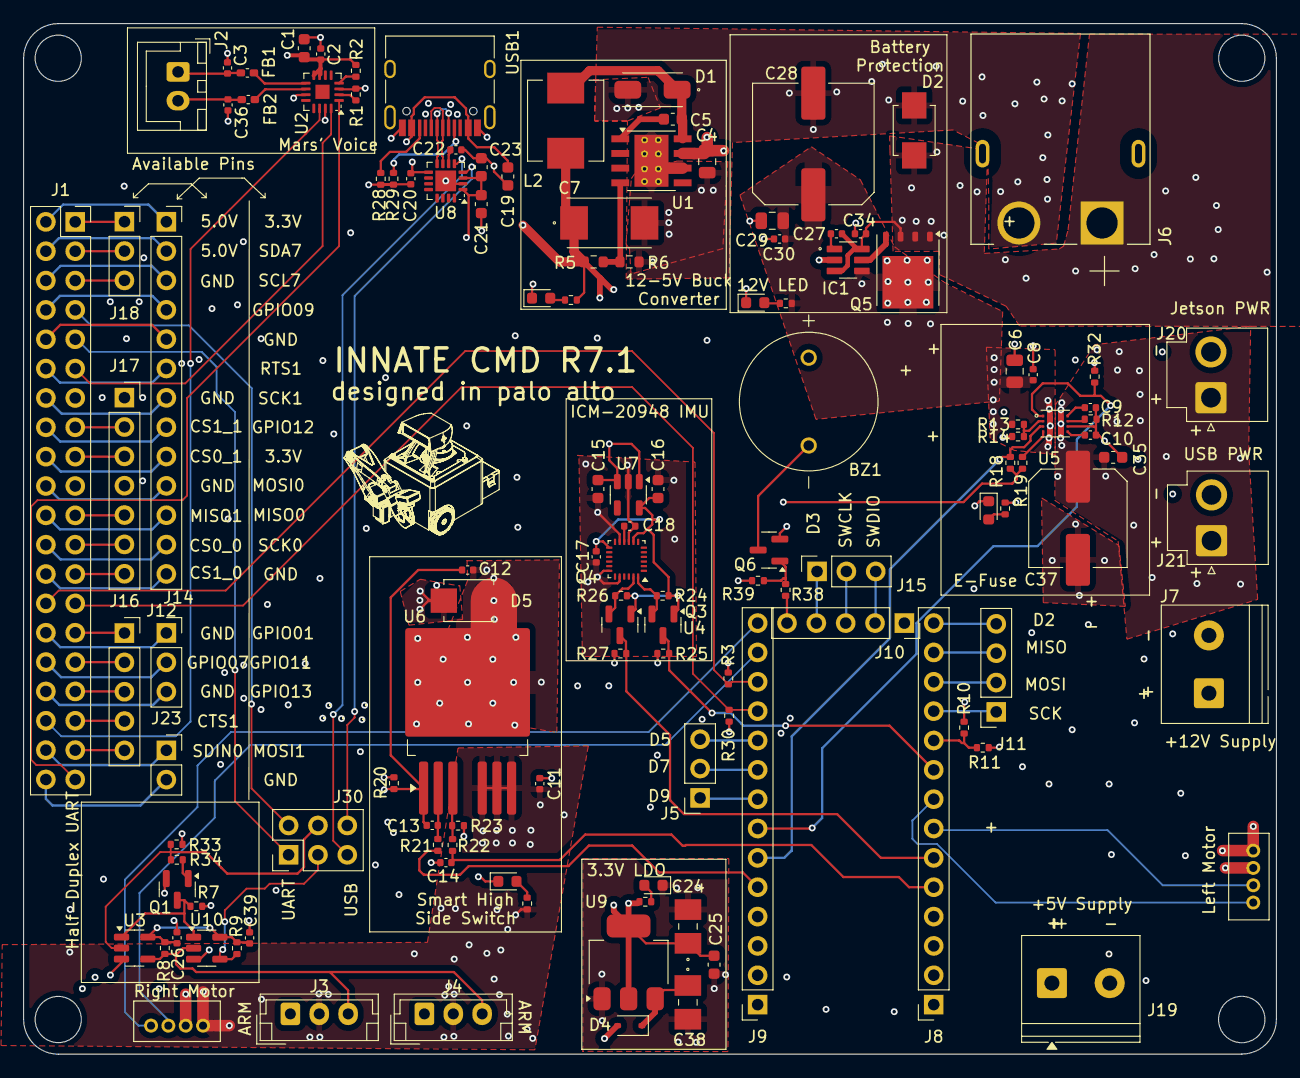
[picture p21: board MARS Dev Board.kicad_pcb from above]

Board: 6 copper layers, 108.4 x 89.2 mm, 126 parts (0 on the bottom side), 105 nets.

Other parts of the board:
C19: 10uF; C_0603_1608Metric
C20, C22: .1uF; C_0402_1005Metric
C21, C23: 1uF; C_0603_1608Metric
R28, R29: 5k1; R_0402_1005Metric
U8: CH343P; WCH_QFN-16-1EP_3x3mm_P0.5mm_EP1.8x1.8mm
USB1: USB_C_Receptacle_HRO_TYPE-C-31-M-12

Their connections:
+3.3V: C21.2, C23.2, U8.1 (VIO), U8.3 (VDD5); also elsewhere on the board
/USB_Control/3v3_OP: C22.2, U8.6 (V3_{OUT})
/USB_Control/CC1: R29.1, USB1.A5 (CC1)
/USB_Control/CC2: R28.1, USB1.B5 (CC2)
/USB_Control/USBD_N: U8.8 (UD-), USB1.A7 (DN1), USB1.B7 (DN2)
/USB_Control/USBD_P: U8.7 (UD+), USB1.A6 (DP1), USB1.B6 (DP2)
CH_RXD: U8.5 (RXD); also elsewhere on the board
CH_TXD: U8.4 (TXD); also elsewhere on the board
GND: C19.1, C20.1, C21.1, C22.1, C23.1, R28.2, R29.2, U8.2 (GND), U8.17 (GND_EPAD), USB1.A1B12 (GND), USB1.B1A12 (GND); also elsewhere on the board
VDDUSB: C19.2, C20.2, U8.9 (VBUS), USB1.A4B9 (VBUS), USB1.B4A9 (VBUS)

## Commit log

2025-10-04 some steps and pcbs
    [B5819WS.stp, C0603.STEP, JST-B3B-EH-A.STEP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]
2025-10-06 main pcb
    [bom.csv, designators.csv, innate dev pcb.kicad_pcb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]
2025-10-06 assembly step files
2025-10-07 readme and bom, still need to do nuts and bolts
2026-04-15 update STEP files
    [Layer4.STEP, head.STEP, layer1.STEP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]
2026-04-15 Update main PCB files
    R5 -> R7.1
    [BTS50010-1TAD.kicad_sch, BatProt.kicad_sch, E-Fuse.kicad_sch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]
2026-06-30 assembly added
    added full assembly STEP file, along with renaming several items
    [B5819WS.stp, C0603.STEP, JST-B3B-EH-A.STEP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]
